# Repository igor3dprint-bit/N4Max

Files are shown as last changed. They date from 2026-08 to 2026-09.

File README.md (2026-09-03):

## ⚠️ Leia antes de qualquer coisa: o risco é seu

Este material é compartilhado de graça, como está, **sem nenhuma garantia**. Ele descreve o que deu
certo em **uma** impressora: a minha.

**Ao seguir qualquer coisa daqui, você assume integralmente a responsabilidade pelo que acontecer
com o seu equipamento.** Isso inclui, sem se limitar a: perda da configuração, impressora que não
liga mais, firmware corrompido, bico enfiado na mesa, chapa riscada, peça danificada, perda de
garantia do fabricante, e prejuízo material ou de tempo.

Nem o autor nem a S&M Makers nem os projetos citados respondem por qualquer dano, direto ou
indireto, decorrente do uso destas instruções.

Mexer em firmware, em sonda e em Z-offset **tem risco real**. Estas páginas existem justamente
porque cada coisa aqui quebrou primeiro na minha máquina. O caminho de volta está documentado em
todos os procedimentos, mas quem está com a mão na impressora é você.

Se você não se sente confortável em ler um comando antes de colar, ou não tem como voltar atrás,
**não faça**. Não tem problema nenhum em manter a impressora como ela veio de fábrica.

*This material is provided free of charge, as is, with no warranty of any kind. By following it you
accept full responsibility for anything that happens to your equipment. Neither the author nor any
project referenced here is liable for any damage, direct or indirect.*

---

# Elegoo Neptune 4 Max: Klipper moderno, BTT Eddy e o Z-offset que não obedece

Tudo o que eu aprendi mexendo na minha Neptune 4 Max, escrito comando por comando, com os números
reais que eu medi na máquina. Não é teoria de fórum: cada coisa aqui quebrou primeiro, e só depois
funcionou.

Autor: [@Igor3DPrint](https://instagram.com/igor3dprint)

[Passo a passo em português](PASSO-A-PASSO.md) · [Step by step in English](STEP-BY-STEP.md) ·
[Página web](https://igor3dprint-bit.github.io/N4Max/)

---

## Crédito antes de tudo

**Sem a S&M Makers, nada disto existiria.** Todo o trabalho de portar o Klipper moderno para a
Neptune 4 Max é dele. Este repositório traduz o processo para o português e acrescenta o que eu
descobri usando a máquina no dia a dia. Se isto te ajudou, o agradecimento vai pra lá.

| | |
|---|---|
| Vídeo | https://www.youtube.com/watch?v=Aoy3sI1lv1g, do **@SandMMakers** |
| Tutorial original | https://sandmmakers.com/Projects/Neptune4MaxLatestKlipper/Directions.html |
| Código | https://github.com/sandmmakers/klipper |

**Menção honrosa: BigTreeTech.** O hardware que faz o Z-offset se medir sozinho é deles: a sonda
BTT Eddy. Sem ela, nem a §3 nem a §4 deste guia existiriam. A minha unidade foi comprada na loja
oficial BIGTREETECH no AliExpress.

*Honorable mention: BigTreeTech, maker of the BTT Eddy probe that makes the self-measuring Z-offset
possible. My unit was bought from BigTreeTech's official store on AliExpress.*

---

## O que tem aqui

### 1. Instalar o Klipper de 2025 no lugar do de 2022

A Neptune 4 Max sai de fábrica com um Klipper de **2022**. O passo a passo leva você até a versão de
**2025**, comando por comando, explicando o que cada um faz e mostrando o que você deve ver na tela.
Sem pendrive, sem chave de fenda, sem abrir a impressora.

| 🇧🇷 PT-BR | 🇺🇸 EN |
|---|---|
| [PASSO-A-PASSO.md](PASSO-A-PASSO.md) | [STEP-BY-STEP.md](STEP-BY-STEP.md) |

### 2. Instalar e calibrar uma sonda BTT Eddy

O Eddy é rápido e preciso, e tem uma limitação que quase ninguém avisa: ele enxerga só os últimos
4 mm. Na Neptune 4 Max, onde a sonda é a única referência de Z da máquina, isso muda tudo.

Este guia cobre a montagem, as três medidas que você precisa tirar, a ordem certa da calibração, e
as quatro armadilhas que me custaram uma noite inteira e um bico arrastado na chapa. Tem ênfase
especial na **corrente de excitação do sensor**, o `reg_drive_current`, que é o parâmetro mais
importante e o menos falado. É a causa mais comum de `Eddy current sensor error` nesta máquina, e a
mensagem parece dizer que o sensor está longe da mesa. Não é isso que ela informa. Com a corrente
errada, o sensor dá erro mesmo estando na distância certa, e você procura horas no lugar errado.

| 🇧🇷 PT-BR | 🇺🇸 EN |
|---|---|
| [EDDY.md](EDDY.md) | [EDDY.en.md](EDDY.en.md) |

### 3. Fazer a máquina achar o Z sozinha, com o eddy-ng

O **BTT Eddy é o hardware**. O **eddy-ng é um software alternativo para esse mesmo hardware** —
mesma bobina, mesmo cabo, mesma peça no toolhead. O que muda é quem interpreta a leitura.

Com o driver padrão, você faz o teste do papel uma vez e guarda o número. Com o eddy-ng, **o bico
encosta na mesa e o zero é medido na hora, a cada impressão**. Isso se chama *tap*, e é o motivo
inteiro de trocar: acaba o teste do papel, e o zero fica certo mesmo trocando de bico ou saindo de
PLA a 60 °C para ABS a 100 °C, porque a medição é feita quente.

Não precisa migrar para o Klipper mainline: instala em cima do fork da S&M Makers. Aqui o tap ficou
com **desvio padrão de 0,006 mm** em três medições — seis micra — mesmo com a bobina montada a
0,94 mm, um terço da altura que a documentação recomenda.

O guia traz a receita completa, o ovo-e-galinha do primeiro homing (a sonda é a única referência de
Z e ela ainda não está calibrada), e as dez coisas que quebraram no caminho, com o que resolveu cada
uma.

| 🇧🇷 PT-BR | 🇺🇸 EN |
|---|---|
| [EDDY-NG.md](EDDY-NG.md) | [EDDY-NG.en.md](EDDY-NG.en.md) |

### 4. O Z-offset que não obedece, e por quê

Nesta máquina você ajusta o Z-offset, salva, e **quase nada muda**. Medido: mudar de `0.0` para
`2.110` deslocou o bico em **0,05 mm** quando deveria deslocar 2,11.

São três causas somadas, e nenhuma delas está documentada em outro lugar. O módulo da tela zera o
valor no `SAVE_CONFIG`, o `plr.cfg` declara a impressora zerada segundos depois de ligar sem ter
homeado, e o `PROBE_CALIBRATE` repete o mesmo valor errado. Tem a solução, como medir o **seu** valor,
e o efeito colateral que enfiou um bico na borracha de limpeza aqui.

[Z-OFFSET.md](Z-OFFSET.md), bilíngue

### 5. Uma máquina de referência inteira

O hardware montado, todos os valores gravados na configuração, cada alteração feita e o motivo dela,
as macros do dia a dia, e o que ficou pendente. É o exemplo completo: os outros documentos ensinam o
procedimento, este mostra uma máquina onde o procedimento já foi até o fim.

[MAQUINA-REFERENCIA.md](MAQUINA-REFERENCIA.md)

E os arquivos de configuração de verdade, copiados da impressora, em [config/](config/) — para você
comparar com os seus quando algo não bater. Vêm com o aviso de sempre: a estrutura serve, os números
são meus.

### 6. Uma IA que conduz você pelo processo

Jogue este repositório inteiro no Claude, no Codex ou no Cursor e peça ajuda. Antes de fazer
qualquer coisa, a IA vai te perguntar **o que você quer**:

> 1. Atualizar o Klipper &nbsp;·&nbsp; 2. Instalar o BTT Eddy &nbsp;·&nbsp; 3. Z-offset não obedece
> &nbsp;·&nbsp; 4. Diagnosticar erro de homing &nbsp;·&nbsp; 5. Macros e qualidade de impressão
> &nbsp;·&nbsp; 6. Migrar para o eddy-ng

Você escolhe, e ela carrega só o documento daquele caminho, segue a ordem certa, e obedece às regras
de segurança que existem porque cada uma custou um prejuízo real aqui. Ela também tem a máquina de
referência acima para explicar de onde vem cada número, em vez de chutar.

Como a IA conduz o trabalho

Funciona com Claude Code, Codex, Cursor, Copilot e qualquer agente que leia um arquivo de contexto
do repositório.

[AGENTS.md](AGENTS.md) · [CLAUDE.md](CLAUDE.md)

---

## O caminho curto

```bash
# 1. entrar na impressora (senha padrao de fabrica: makerbase)
ssh mks@SEU_IP

# 2. descobrir o firmware Elegoo instalado
grep -rhoE "1\.[0-9]+\.[0-9]+\.[0-9]+" /home/mks/Desktop/myfile/ 2>/dev/null | sort | uniq -c | sort -rn | head -1

# 3. ver quais versoes do port existem para ele
git ls-remote --tags https://github.com/sandmmakers/klipper.git | grep -oE 'sandmmakers-[A-Za-z0-9.-]+' | grep -v '\^{}' | sort -u
```

A partir daqui, siga o [passo a passo](PASSO-A-PASSO.md). Os próximos comandos mexem na máquina e a
ordem importa.

---

## Estrutura

| Arquivo | Conteúdo |
|---|---|
| `PASSO-A-PASSO.md` | Guia completo de instalação do Klipper, comando por comando |
| `STEP-BY-STEP.md` | O mesmo guia, em inglês |
| [EDDY.md](EDDY.md) · [EDDY.en.md](EDDY.en.md) | Instalação e calibração do BTT Eddy, com as armadilhas |
| [EDDY-NG.md](EDDY-NG.md) · [EDDY-NG.en.md](EDDY-NG.en.md) | Trocar o driver do Eddy pelo eddy-ng: tap, Z-offset automático, e os 10 erros do caminho |
| `config/` | Os arquivos de configuração reais da máquina, sanitizados |
| `Z-OFFSET.md` | O Z-offset que não obedece: causas, solução, medição. Bilíngue |
| `MAQUINA-REFERENCIA.md` | A máquina do autor por inteiro: hardware, valores, alterações, macros |
| `AGENTS.md` | Instruções para uma IA conduzir qualquer um dos seis caminhos |
| `CLAUDE.md` | Ponteiro de uma linha para o `AGENTS.md` |
| `docs/` | A página web deste repositório |

---

## Por que comandos, e não um instalador de um clique

Um instalador promete "clica e funciona". Essa promessa exige testar a instalação inteira numa
máquina de fábrica, várias vezes, e eu tenho uma impressora só, em produção.

Comando na tela promete outra coisa: **você está no comando, aqui está o que vai rodar e por quê.**
Essa promessa eu consigo sustentar. Você lê antes de colar, entende o que mudou, e sabe onde parar se
algo sair diferente do esperado. De quebra funciona em Mac e Linux, não só Windows.

---

## Um aviso sobre os números deste repositório

Todo valor numérico aqui foi medido na minha máquina. Os que mais mudam de impressora para
impressora são `x_offset`, `y_offset`, `z_offset`, `reg_drive_current`, a altura de montagem da
sonda e o ponto usado no homing.

Copiar esses números direto, sem medir, é a forma mais rápida de reproduzir os meus erros em vez dos
meus acertos. Use a explicação, meça o seu.

---

## English

This repository documents three things about the Elegoo Neptune 4 Max: installing modern Klipper
over the factory 2022 build, installing and calibrating a BTT Eddy probe, and fixing the Z-offset
that refuses to obey when you save it.

The Klipper install guide, the Eddy guides, and the Z-offset write-up are available in English. The
reference machine and the AI instructions are currently Portuguese only, but any AI agent reading this
repository will answer you in English.

[STEP-BY-STEP.md](STEP-BY-STEP.md) · [EDDY.en.md](EDDY.en.md) · [EDDY-NG.en.md](EDDY-NG.en.md) ·
[Z-OFFSET.md](Z-OFFSET.md)

All the porting work belongs to [S&M Makers](https://github.com/sandmmakers/klipper). This repository
walks through their process and adds what I found living with the machine.

---

## Licença e garantia

Código sob [MIT](LICENSE). O Klipper em si é GPLv3, e o port é da S&M Makers, sob a licença dele.

**Sem garantia, e a responsabilidade é sua.** Como está escrito no topo desta página: ao seguir
qualquer procedimento daqui, você assume integralmente o risco e as consequências para o seu
equipamento. O autor não responde por dano de nenhum tipo.

Mexer em firmware e em sonda tem risco. O caminho de volta existe e está documentado, mas quem está
do lado da impressora é você. Vá devagar, leia antes de colar, e pare quando ficar estranho.

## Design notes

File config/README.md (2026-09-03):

# Os arquivos reais da minha Neptune 4 Max

Esta pasta é o acervo: a configuração **de verdade** da máquina onde este repositório foi escrito,
copiada da impressora, não digitada à mão para o tutorial. Serve para você comparar quando algo não
bate, ou para ver como uma coisa ficou depois de pronta.

Estado destes arquivos: **03/09/2026**, com Klipper da S&M Makers rodando em Python 3, BTT Eddy com
o driver [eddy-ng](../EDDY-NG.md), e a borracha de limpeza já removida da máquina.

---

## ⚠️ Leia antes de copiar qualquer coisa

**Estes arquivos não servem para colar na sua impressora.** Sério. Alguns valores aqui são medidas
físicas da *minha* montagem, e usar os meus é a forma mais rápida de enfiar um bico na sua chapa:

| Valor | Por que é só meu |
|---|---|
| `x_offset` / `y_offset` | Depende de qual adaptador você imprimiu e de como ele ficou |
| `reg_drive_current` / `tap_drive_current` | Sai da calibração da *sua* bobina, na *sua* altura |
| `calibration_17` / `calibration_18` | A curva medida do meu sensor. Não tem significado no seu |
| `[bed_mesh default]` | O empeno da minha chapa |
| `position_endstop`, limites dos eixos | Da minha máquina, com as minhas peças |
| `serial:` do Eddy | Foi trocado por um marcador. O seu sai de `ls /dev/serial/by-id/` |

Use como **referência de estrutura e de ordem**: onde a seção fica, o que vem antes do quê, como um
comentário explica a decisão. Os números, meça os seus.

---

## O que tem em cada arquivo

| Arquivo | O que é |
|---|---|
| `printer.cfg` | A configuração principal. ~1.200 linhas, com os comentários de cada decisão e a data. É o arquivo mais útil aqui, e o mais perigoso de copiar |
| `eddy.cfg` | Só o BTT Eddy: MCU, a seção `[probe_eddy_ng]` e o `[bed_mesh]`. Incluído pelo `printer.cfg` |
| `eddyng_macros.cfg` | As macros do fluxo novo: `PRINT_START` com tap, `LINHA_KAMP` (purga) e `ZoffNGEddy` (z-offset guiado). Incluído por último, de propósito |
| `moonraker.conf` | Praticamente de fábrica. Está aqui só para mostrar que não precisa de mágica |
| `plr.cfg` | Recuperação de queda de energia, da Elegoo. **Não é meu e tem armadilha** — veja abaixo |
| `KAMP_Settings.cfg` | Herança do KAMP. O include está **desligado** hoje; a purga é a `LINHA_KAMP` |

---

## Três coisas para reparar quando for ler

**1. O `printer.cfg` é um diário, não um arquivo limpo.** Cada bloco tem um comentário com a data e
o motivo. Isso é de propósito: seis meses depois, o comentário é a única coisa que explica por que
aquele número é aquele. Vale mais que um arquivo bonito. Repare especialmente no `[stepper_z]`, que
tem um aviso comprido sobre um quase-acidente.

**2. Tem macro obsoleta lá dentro, e ela ficou de propósito.** `LIMPAR_BICO`, `PURGA_BAMBU`,
`LINHA_PURGA` e `EDDY_OFFSET_FULL` eram do tempo da borracha de limpeza, que **não existe mais na
máquina**. Nada chama elas hoje. Deixei porque o histórico ensina — mas se você copiar o
`printer.cfg` inteiro achando que está tudo ativo, vai se perder.

**3. `MANTER_MESA_50` mantém a mesa a 50 °C o tempo todo.** É um `[delayed_gcode]` que se re-arma a
cada 60 segundos. Foi decisão minha (a mesa desta máquina demora muito para aquecer), e me enganou
depois: passei uma sessão inteira achando que a mesa esquentava sozinha por bug. Se você copiar isso
sem querer, sua mesa vai ficar ligada para sempre. Comente o bloco.

**4. O `plr.cfg` zera o Z-offset.** O `RESUME_INTERRUPTED` começa com `SET_GCODE_OFFSET Z=0` e **não
passa por `G28`**. Retomar uma impressão depois de queda de luz continuava com o offset zerado até o
fim. Com o eddy-ng isso importa menos (o zero vem do tap), mas o arquivo está aqui inteiro para você
ver o que a Elegoo colocou na máquina.

---

## Como comparar com a sua

Em vez de abrir os dois lado a lado, baixe o seu e faça o diff só da seção que te interessa:

```bash
# baixe o seu (pelo Moonraker, sem precisar de SSH)
curl -s "http://SEU_IP/server/files/config/printer.cfg" -o meu-printer.cfg

# compare só uma seção
diff <(sed -n '/^\[stepper_z\]/,/^\[/p' meu-printer.cfg) \
     <(sed -n '/^\[stepper_z\]/,/^\[/p' printer.cfg)
```

---

## Sobre privacidade

Estes arquivos foram varridos antes de subir: sem senha, sem token, sem chave, sem rede de casa, sem
e-mail. O único identificador de hardware que existia — o número de série USB do Eddy — foi trocado
por um marcador, e de todo jeito você precisa do **seu**.

A senha `makerbase` que aparece nos guias é a de fábrica da Elegoo, igual em toda Neptune. Se a sua
impressora fica exposta na internet, troque — mas isso vale desde antes deste repositório existir.

---

Crédito do Klipper moderno nesta máquina: [S&M Makers](https://github.com/sandmmakers/klipper).

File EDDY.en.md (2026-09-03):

# BTT Eddy Duo on the Elegoo Neptune 4 Max

Author [@Igor3DPrint](https://instagram.com/igor3dprint)

> **This guide uses the driver that comes with Klipper (`probe_eddy_current`), and it is still valid:
> this is where you start.** Two things changed on the reference machine after it was written, on
> 03/09/2026, and you should know them before reading:
>
> - It moved to **[eddy-ng](EDDY-NG.en.md)**, where the Z-offset measures itself on every print. If
>   your final goal is to stop calibrating Z, install it first by following this document and then go
>   to [EDDY-NG.en.md](EDDY-NG.en.md).
> - The **nozzle-cleaning pad was removed** from the machine. The nozzle-cleaning macros mentioned
>   later (`LIMPAR_BICO`, `PURGA_BAMBU`, `EDDY_OFFSET_FULL`) still exist in the configuration, but
>   nothing calls them anymore. They are not an error; they are history.

This guide covers installing the BTT Eddy Duo probe on the Neptune 4 Max running modern Klipper. It
is written in the order things happen, with the numbers I measured on my machine and the mistakes I
made before reaching them.

A summary before anything else. The parameter that cost me the most time was the coil drive current,
`reg_drive_current`. With it wrong, the sensor reports a failure even with the nozzle at the right
distance, and the error message points to the wrong place. It is in [topic 9](#9-the-drive-current).

> Saw `Eddy current sensor error`? Run `LDC_CALIBRATE_DRIVE_CURRENT CHIP=btt_eddy` before changing
> any height. The command does not move the machine, so it is safe to run at any time, and this is the
> most common cause of that error on this machine. Full detail in [topic 9](#9-the-drive-current).

---

## Topics

1. [Hardware I used](#1-hardware-i-used)
2. [Printed part](#2-printed-part)
3. [How the Eddy appears on the computer](#3-how-the-eddy-appears-on-the-computer)
4. [What the Eddy does and does not do](#4-what-the-eddy-does-and-does-not-do)
5. [The three mounting measurements](#5-the-three-mounting-measurements)
6. [The base configuration](#6-the-base-configuration)
7. [The calculations that prevent sensor errors](#7-the-calculations-that-prevent-sensor-errors)
8. [The calibration order](#8-the-calibration-order)
9. [The drive current](#9-the-drive-current)
10. [Four Neptune 4 Max traps](#10-four-neptune-4-max-traps)
11. [Homing and the first-home ritual](#11-homing-and-the-first-home-ritual)
12. [The dense mesh](#12-the-dense-mesh)
13. [Macros I use day to day](#13-macros-i-use-day-to-day)
14. [How to measure whether the calibration came out good](#14-how-to-measure-whether-the-calibration-came-out-good)
15. [Symptom table](#15-symptom-table)

---

## 1. Hardware I used

**BTT Eddy Duo** probe, from BigTreeTech. The Duo version connects over **USB**, directly to the
printer board or to the host. It does not need a data wire connected to the Neptune motherboard,
which simplifies the installation a lot.

It appears in Klipper as a separate MCU, with its own serial.

```ini
[mcu eddy]
serial: /dev/serial/by-id/usb-Klipper_rp2040_SEU_ID_AQUI-if00
```

To discover your ID, with the probe plugged in, run this inside the printer.

```bash
ls /dev/serial/by-id/
```

---

## 2. Printed part

The mount that holds the Eddy on the Neptune 4 extruder carriage, the only STL needed for this
build.

https://www.printables.com/model/928061-neptune-4-btt-eddy-adapter

Print it in **ABS or ASA**. The part sits close to the hot nozzle and near the heated bed, and PLA
softens and deforms in that temperature range, which takes the precision out of the geometry that
holds the probe. PETG is a middle ground and still creeps under sustained heat.

There are two variants in the model, one straight and one at ninety degrees. I printed and used the
straight one. Choose based on the clearance left on your carriage, because the variant changes the
adapter position and with it the coil mounting height, and that height goes into every calculation
in [topic 7](#7-the-calculations-that-prevent-sensor-errors). Measure your height after mounting. Do
not copy mine.

It takes **2 M3 heat-set inserts**, melted in with a soldering iron.

---

## 3. How the Eddy appears on the computer

This point deserves attention because it is where many people get stuck before even starting.

The **BOOT button on the Eddy Duo is on the top side of the board**. It does not appear on the
computer by itself when you only plug in the cable. The sequence that works is this.

1. With the USB cable disconnected, press and hold the BOOT button
2. Without releasing the button, plug the USB cable into the computer
3. Release the button

Eddy Duo BOOT button sequence: USB disconnected, hold the button, plug in USB, release the button

Now it appears, and you can flash Klipper firmware to it.

If you plug in USB first and only then press the button, it does not enter flashing mode. That is
what happened to me on the first try, and I spent a while thinking the board was defective.

After it is flashed, it starts appearing normally in `/dev/serial/by-id/` every time the printer
turns on, without needing any button.

---

## 4. What the Eddy does and does not do

The Eddy measures distance through eddy current induced in a coil. It reads fast, repeats well, and
does not touch anything.

The limitation almost nobody warns you about is range. It sees **only the last few millimeters**. On
my machine, the calibrated range goes from 0.05 mm to 4.05 mm. Above that, the chip does not see the
bed, sets the error bits, and Klipper aborts.

That leads to the sentence that summarizes the whole guide.

> The Eddy does not work by itself as a Z endstop.

A mechanical endstop triggers from any height. The Eddy does not trigger, because from far away there
is no reading to compare.

On the Neptune 4 Max this matters, because the factory `[stepper_z]` uses
`endstop_pin: probe:z_virtual_endstop`, meaning the probe is the only Z reference the machine has.
If you remove the original probe when installing the Eddy, as I did, you create a loop. To home, the
nozzle needs to be close, and to know it is close, Z needs to be homed.

[Topic 11](#11-homing-and-the-first-home-ritual) shows how to break that loop. If you can keep the
original probe installed in parallel, keep it, and you skip that entire topic.

One detail fooled me. After removing the old probe, its pin remains on the board and remains being
read. An input with a pull-up resistor and nothing plugged in floats high, which makes Klipper
believe an endstop is triggered. Do not trust what the pin reports; trust what is bolted to the
machine.

> **Do not try to use the removed probe's pin as an endstop.** I tried it here, pointing
> `[stepper_z]` to the old probe pin with the end empty. The axis went down and did not stop, because
> the pin held high by pull-up never changes state, and I had to cut power to the printer. Only use
> that pin again after you have a real sensor bolted to its end.

---

## 5. The three mounting measurements

After bolting the adapter on, you need three numbers. Getting any of them wrong makes the whole mesh
measure the wrong place.

### Coil height

Touch the nozzle to the bed and measure how far the face of the coil sits above the tip of the
nozzle. Mine was **0.94 mm**. BigTreeTech recommends between two and three millimeters.

I went lower by choice, and that reduces maneuvering clearance. With 0.94 mm, when the nozzle is
three millimeters from the bed, the coil is at 3.94 mm, almost at the 4.05 mm limit it can see.

Save that number, because it goes into every calculation in the next topic.

```
coil height = nozzle height + mounting height
```

Side view of the coil, the bed, and the 0.05 to 4.05 mm reading range

The image shows why a probing descent that starts above that range fails on the first sample: the
chip has no reading to compare at that height.

### X offset

Measure from the center of the nozzle to the center of the coil, horizontally. Mine measured
**33.34 mm**.

The sign is confusing. The rule I use is to look at `[stepper_x]` in `printer.cfg`. With
`position_endstop: 0` and `homing_positive_dir: false`, the endstop is on the side where X equals
zero, meaning the left side. If the coil is on the same side as the endstop, it sits left of the
nozzle, and `x_offset` is **negative**.

In my case it became `x_offset: -33.34`.

### Y offset

This is the one almost everyone assumes is zero. I assumed that too, and later redid a whole mesh
because of it. Measure.

On mine, the Eddy sits **behind** the nozzle and measured **20 mm**. Behind means the coil covers a
point on the plate with a larger Y than the nozzle's Y, so `y_offset` is **positive**.

In my case it became `y_offset: 20`.

I ran a full mesh with `y_offset` at zero when the correct value was twenty. Every point was measured
twenty millimeters away from its intended place. The mesh looked normal on screen and was wrong
everywhere.

---

## 6. The base configuration

I keep the Eddy in a separate file called `eddy.cfg`, with an `[include eddy.cfg]` in `printer.cfg`.
That makes it easier to compare and roll back.

```ini
[mcu eddy]
serial: /dev/serial/by-id/usb-Klipper_rp2040_SEU_ID_AQUI-if00

[probe_eddy_current btt_eddy]
sensor_type: ldc1612
i2c_mcu: eddy
i2c_bus: i2c0f
x_offset: -33.34
y_offset: 20
speed: 5.0
samples: 2
samples_result: median
sample_retract_dist: 1.0

[bed_mesh]
speed: 200
horizontal_move_z: 2.5
mesh_min: 20,25
mesh_max: 390,410
probe_count: 6,6
algorithm: bicubic
bicubic_tension: 0.2
mesh_pps: 2, 2
fade_start: 5.0
fade_end: 30.0
```

Notice that **there is no `z_offset` in this block**, and that is intentional. The reason is in
[trap 4](#trap-4-z_offset-written-by-hand-locks-save_config).

### Why mesh_max does not cover the whole plate

The plate is 420 mm, but the measurable area is smaller, and the probe geometry is why. Klipper
calculates it like this.

```
nozzle position = mesh point minus the axis offset
```

With `x_offset: -33.34`, the nozzle needs to go to `point + 33.34`. X `position_max` is 430.1, so the
rightmost measurable point is around 396. I use 390 to leave margin, which takes the nozzle to
423.34.

With `y_offset: 20`, the nozzle goes to `point - 20`. A Y `mesh_min` of 25 takes the nozzle to 5,
almost touching the front stop.

The lower X limit has a reason too. With `mesh_min` in X below 20, the coil would pass over the
cleaning pad, which is seven millimeters tall, during the scan.

Top view of the plate, with the nozzle position against the coil position and the resulting mesh area

---

## 7. The calculations that prevent sensor errors

Three inequalities. Call `F` the top of the calibrated range, which on my machine is 4.05, and `M`
the coil mounting height, which on mine is 0.94.

```
z_offset + sample_retract_dist   <  F
horizontal_move_z + M            <  F
starting height for the descent + M <  F
```

If any of them overflows, the sensor will report an error at some point in the cycle, and the symptom
will look like something completely different.

### First calculation, sample_retract_dist

With `samples: 2`, Klipper probes, rises by this amount, and probes again. The trigger happens with
the coil reading the `z_offset` value. If the retract is too large, the second probe starts outside
the range.

The factory default is 3.0. With `z_offset` near 2.0, that gives 5.0 and overflows. I use **1.0**.

### Second calculation, horizontal_move_z

This is the nozzle height while traveling between mesh points. Add the mounting height to know where
the coil is.

The ten-millimeter default would put the coil at 10.94 mm, blind. I use **2.5**, which results in
3.44 mm.

### Third calculation, the starting height for the descent

This is defined by the `z_hop` in `safe_z_home`, or by your `homing_override`. With a 0.94 mm mount,
starting the descent at three millimeters leaves the coil at 3.94 mm, inside the range but with
little margin.

---

## 8. The calibration order

This is the part I did in the wrong order and that cost me a whole night.

1. Write the base configuration with the measured offsets
2. Calibrate the drive current with `LDC_CALIBRATE_DRIVE_CURRENT CHIP=btt_eddy` and run
   `SAVE_CONFIG`
3. Only then build the table with `PROBE_EDDY_CURRENT_CALIBRATE CHIP=btt_eddy` and run `SAVE_CONFIG`
4. Test homing
5. After that, the mesh

Never the opposite, and never only one of the two calibrations.

The drive current defines the signal amplitude, and changing it shifts all frequencies. If you build
the table first and change the current afterward, the table is no longer valid.

The worst part is that it does not warn you. It starts triggering at the wrong height, which means
nozzle against the sheet.

> Changed `reg_drive_current`, the table is dead. Redo `PROBE_EDDY_CURRENT_CALIBRATE` before sending
> any `G28`.

---

## 9. The drive current

**This is the parameter that knocks the most people down on this machine.** If you came here directly
from a sensor error, read this whole topic before changing any height, retract, or offset.

The LDC1612 excites the coil with a configurable current called `reg_drive_current`, which is an
integer from zero to thirty-one. It needs to match your coil, your mounting height, and your bed.

Current that is **too high** saturates the amplitude. Current that is **too low** kills the signal.
In both cases, the chip sets an error bit and Klipper returns this.

```
Error during homing z: Eddy current sensor error
```

Here is the trap. That message sounds like it says the sensor is far from the bed, and that is not
what it reports. In my case the nozzle was at two millimeters, inside the range, and the error still
happened. I spent hours changing height, bed temperature, and retract distance, when the problem was
the signal gain.

If you want to confirm at the source, the error starts in the firmware, in `src/sensor_ldc1612.c`.

```c
if (data > 0x0fffffff) {
    // Sensor reports an issue - cancel homing
    ld->homing_flags = 0;
    trsync_do_trigger(ld->ts, ld->error_reason);
    return;
}
```

The four high bits are the chip's own error bits. Notice that the test comes **before** any movement,
so it aborts on the first sample. That is why the symptom looks like "it does not go down and already
errors". Also notice that this has no relation to the `calibrate` table, because the hardware is
complaining; Klipper is not comparing numbers.

### How to measure without moving the machine

There is a command that makes the chip itself choose the right value, in the position where it
already is, without moving anything.

```
LDC_CALIBRATE_DRIVE_CURRENT CHIP=btt_eddy
```

The response appears in the console.

```
probe_eddy_current btt_eddy: reg_drive_current: 16
```

Compare it with what is in your configuration. In my case it was eighteen and the chip wanted
sixteen. A two-point difference locked everything up.

The number is not fixed forever. After remounting the probe and remeasuring `x_offset` and
`y_offset`, I ran the command again and it pointed back to eighteen. Treat any value in this guide as
a snapshot, not a constant. Every time the physical mount changes, measure again before trusting the
old number, yours or mine.

### Where this command lives

If you look for this command inside `probe_eddy_current.py`, you will not find it, and it is easy to
conclude your Klipper fork does not have it. It lives in `ldc1612.py`, which is the chip driver.

```bash
grep -n "LDC_CALIBRATE_DRIVE_CURRENT" ~/klipper*/klippy/extras/ldc1612.py
```

I almost abandoned this line of investigation because I searched in the wrong file.

### After measuring

Run `SAVE_CONFIG`. The printer restarts with the new value. Then redo the table, as shown in
[topic 8](#8-the-calibration-order). Do not skip that part.

---

## 10. Four Neptune 4 Max traps

Listed in the order they appeared here, because one hid the next. If you have
`Eddy current sensor error` and already checked the height, it is very likely one of these.

### Trap 1, the printer declares itself zeroed at boot

In the Neptune `printer.cfg` and `plr.cfg`, this block exists.

```ini
[delayed_gcode KINEMATIC_POSITION]
initial_duration: 3.0
gcode:
      SET_KINEMATIC_POSITION X=110
      SET_KINEMATIC_POSITION Y=110
      SET_KINEMATIC_POSITION Z=0
```

A few seconds after power-up, Klipper starts believing Z is at zero, with the nozzle physically
thirty millimeters from the bed. When you send `G28`, `safe_z_home` concludes Z is already homed,
that zero is lower than `z_hop`, and **raises** the nozzle to "three", which in real life is
thirty-three. The coil sees nothing and aborts.

The symptom is very characteristic. It homes X and Y, returns to the middle, does not descend, and
immediately errors.

Comment out the whole block in both files. It appears duplicated, and the one that counts is the one
in `printer.cfg`, because it comes later in the read order. Commenting only one does not solve it.

The same block is also the root cause of the Z-offset that appears ignored on this machine, with the
full explanation in
[Z-OFFSET.md](Z-OFFSET.md#2-a-impressora-se-declara-zerada-alguns-segundos-depois-de-ligar-sem-ter-homeado).

### Trap 2, an old Z compensation applied blindly

I had this in `printer.cfg`, from when I used the contact probe.

```ini
[gcode_macro G28]
rename_existing: G28.1
gcode:
    G28.1 {rawparams}
    SET_GCODE_OFFSET Z=-1.95
```

After changing probes, it kept being applied. Every `G0 Z` started going down 1.95 mm more than I
commanded. That is how I dragged the nozzle across the sheet while trying to position manually.

Check the active value on your machine now.

```bash
curl -s "http://SEU_IP/printer/objects/query?gcode_move" | grep -o '"homing_origin": \[[^]]*\]'
```

If the third number is not `0.0`, there is a hidden offset eating into your descent. Zero it before
sending any manual Z movement.

### Trap 3, the retract between the two homing passes

`[stepper_z]` comes with `homing_retract_dist: 5`.

Klipper hits the trigger, rises by that much, and makes a second slow pass to confirm. With the
trigger at two millimeters of reading, rising five takes the coil to seven, outside the range. The
second pass starts blind and the chip aborts.

The symptom is deceptive because the **first pass works**. You see the machine descend, touch, and
only then error. It looks like a trigger problem and is a retract problem.

I use **1.5**, which leaves the coil at 3.5 mm.

### Trap 4, z_offset written by hand locks SAVE_CONFIG

If you write `z_offset` in `eddy.cfg`, which is an included file, every `SAVE_CONFIG` after a
`PROBE_CALIBRATE` will fail with this message.

```
SAVE_CONFIG section 'probe_eddy_current btt_eddy' option 'z_offset' conflicts with included value
```

Klipper does not autosave over a value that came from an include. Calibration runs, shows the new
number, and cannot save it.

The solution is to leave `z_offset` out of `eddy.cfg` and allow it to live in the autosave block at
the end of `printer.cfg`. If you are migrating from a configuration that already had the value
written by hand, remove the line from the included file and add the value to the autosave block.

```
#*# [probe_eddy_current btt_eddy]
#*# z_offset = 0.300
#*# reg_drive_current = 18
```

---

## 11. Homing and the first-home ritual

If your original probe was removed, the first `G28` after power-up cannot work by itself, because
there is no Z reference and the coil only sees four millimeters.

The cycle without a contact probe, and how to break it

What works, and is safe, is homing X and Y first and then **descending while watching**.

```
G28 X Y
G0 X215 Y215 F6000
```

Now lower Z from the panel, watching the nozzle, until it is about two millimeters from the bed. Use
steps of ten only while it is clearly far away, then one, then zero point one. Then:

```
G28 Z
```

After that, Z is homed, and the printer works normally until you turn it off.

> Never send an absolute `G0 Z` to a height calculated in your head while Z is not trustworthy. That
> is exactly how I dragged the nozzle. Small step, eyes on the nozzle, and stop if it touches.

### Separating travel clearance from descent height

If you have something tall on the bed near the origin, like the cleaning pad, the `z_hop` in
`safe_z_home` creates a deadlock. It is both the travel clearance to the endstop and the starting
height for the descent. You need high clearance for travel and low height for probing, and one number
does not solve both.

The way out is to replace `safe_z_home` with a `homing_override`.

```ini
[homing_override]
axes: xyz
gcode:
    {% set tudo = 'X' not in params and 'Y' not in params and 'Z' not in params %}
    {% set z_tinha_referencia = 'z' in printer.toolhead.homed_axes %}
    {% if not z_tinha_referencia %}
        SET_KINEMATIC_POSITION Z=0
    {% endif %}
    G91
    G0 Z16 F600
    G90
    {% if tudo or 'X' in params %}
        G28 X
    {% endif %}
    {% if tudo or 'Y' in params %}
        G28 Y
    {% endif %}
    {% if tudo or 'Z' in params %}
        {% if not z_tinha_referencia %}
            { action_raise_error("Z has no reference. The Eddy only sees up to 4mm, so blind descent does not work. X and Y are already homed. Lower the nozzle from the panel to about 2mm from the bed and run G28 Z.") }
        {% endif %}
        G0 X239.25 Y194.55 F6000
        G91
        G0 Z-16 F600
        G90
        G28 Z
    {% endif %}
```

Adjust `G0 X239.25 Y194.55` to your machine's probing point.

This version gained a guard. When Z has no reference at all, it homes X and Y normally and **stops**,
with written instructions instead of diving blindly. That turns a confusing `Eddy current sensor
error` into a message that says what to do: lower the nozzle from the panel until it is near the bed
and run `G28 Z` by hand, as described at the start of this topic.

The logic in plain English. It rises sixteen millimeters relative, which is safe from any height,
including with virgin Z. It homes X and Y with full clearance over the pad. It returns to the probing
point. It descends the same sixteen millimeters relative, putting the nozzle exactly back at the
height it left from. Then it probes.

Notice that **there is no descent to an absolute height** inside here. I did write a version that
descended to Z equal to three when Klipper thought Z was known, and that is dangerous, because a
reference declared by hand with `SET_KINEMATIC_POSITION` also counts as known. The descent would turn
into a dive of dozens of millimeters into the bed.

Whoever knows Z itself is trustworthy, like a print-start macro that just homed, positions itself
before calling `G28 Z`.

`safe_z_home` and `homing_override` cannot coexist. Comment out one to use the other.

---

## 12. The dense mesh

A contact probe takes almost a second per point. The Eddy scans in continuous motion, and this is
where it pays for itself. You can measure thousands of points in the time the bed takes to stabilize.

```ini
[gcode_macro EDDY_MALHA]
description: Dense mesh of the whole usable area. Ex, EDDY_MALHA BED=50 SOAK=300
variable_pontos: 70
gcode:
    {% set c = printer['gcode_macro EDDY_MALHA'] %}
    {% set bed = params.BED|default(50)|float %}
    {% set soak = params.SOAK|default(300)|int %}
    {% set n = params.PONTOS|default(c.pontos)|int %}
    M117 Heating the bed
    M140 S{bed}
    TEMPERATURE_WAIT SENSOR=heater_bed MINIMUM={bed - 1} MAXIMUM={bed + 1}
    M117 Soak
    G4 P{soak * 1000}
    M117 Homing
    G28
    BED_MESH_CLEAR
    M117 Scanning the bed
    _BED_MESH_CALIBRATE METHOD=rapid_scan HORIZONTAL_MOVE_Z=2.5 PROBE_COUNT={n},{n} MESH_PPS=0 SCAN_SPEED=200
    M400
    RESPOND TYPE=command MSG="Mesh ready. Run SAVE_CONFIG to save."
```

Normal use.

```
EDDY_MALHA
SAVE_CONFIG
```

That is 4900 points over an area of 370 by 385 millimeters, about 5.3 mm spacing. Against the factory
six by six, which gives seventy-three millimeters of spacing, the difference is large.

Three notes that apply to any machine.

`rapid_scan` is only enabled when the probe is of type `probe_eddy_current`. With a contact probe,
Klipper falls back to the normal method without warning.

`HORIZONTAL_MOVE_Z` is the **nozzle** height during the scan, not the coil height. Redo the
calculation from [topic 7](#7-the-calculations-that-prevent-sensor-errors) with your mounting
height.

The routine time is mostly soak, and soak is what makes the mesh worth anything. A cold bed measures
one surface; a stabilized bed measures another. A half-hour routine with five minutes of scanning is
time well spent.

---

## 13. Macros I use day to day

### Nozzle cleaning on the pad

Runs the nozzle over the silicone pad. Accepts parameters so it can be reused in other contexts.

```ini
[gcode_macro LIMPAR_BICO]
description: Cleans the nozzle on the pad
variable_x: 2.5
variable_y_ini: 5
variable_y_fim: 30
variable_z: 6.0
variable_passadas: 10
variable_temp: 150
gcode:
    {% set c = printer['gcode_macro LIMPAR_BICO'] %}
    {% set t = params.TEMP|default(c.temp)|float %}
    {% set n = params.PASSADAS|default(c.passadas)|int %}
    {% if 'xyz' not in printer.toolhead.homed_axes %}
        { action_raise_error("LIMPAR_BICO, axes not homed") }
    {% endif %}
    {% if t > 0 %}
        M109 S{t}
    {% endif %}
    G90
    G0 Z{c.z + 6} F1200
    G0 X{c.x} Y{c.y_ini} F6000
    G0 Z{c.z} F600
    {% for i in range(n) %}
        G0 Y{c.y_fim} F6000
        G0 Y{c.y_ini} F6000
    {% endfor %}
    G0 Z{c.z + 10} F1200
```

With `TEMP=0`, it does not change temperature, which allows calling it in the middle of a print.

`variable_z` sits one millimeter below the height of the pad, which gives the interference that makes
the scraping happen. With a seven-millimeter pad, I use six.

### Block purge in the dead corner

Drops old filament in a corner and then cleans the nozzle. It is the Bambu collector idea adapted.

```ini
[gcode_macro PURGA_BAMBU]
description: Block purge in the corner and clean the nozzle. Ex, PURGA_BAMBU Q=50
variable_x: 0
variable_y: 45
variable_z: 15
variable_quantidade: 50
variable_velocidade: 150
variable_altura_segura: 15
gcode:
    {% set c = printer['gcode_macro PURGA_BAMBU'] %}
    {% set q = params.Q|default(c.quantidade)|float %}
    {% if 'xyz' not in printer.toolhead.homed_axes %}
        { action_raise_error("PURGA_BAMBU, axes not homed") }
    {% endif %}
    {% if printer.extruder.temperature < 170 %}
        { action_raise_error("PURGA_BAMBU, nozzle too cold to extrude") }
    {% endif %}
    SAVE_GCODE_STATE NAME=purga_bambu
    G90
    G0 Z{c.altura_segura} F1200
    G0 X{c.x} Y{c.y} F6000
    G0 Z{c.z} F600
    M83
    G1 E{q} F{c.velocidade}
    G1 E-1.5 F2100
    G4 P1500
    G0 Z{c.altura_segura} F1200
    LIMPAR_BICO TEMP=0 PASSADAS=4
    G92 E0
    RESTORE_GCODE_STATE NAME=purga_bambu MOVE=1 MOVE_SPEED=200
```

Purge height changes the result a lot. At two millimeters, the material forms a blob stuck to the
sheet. At fifteen millimeters, it comes out as a strand and barely touches, which is close to Bambu's
behavior. I use fifteen.

I took the volume from the Bambu Lab A1's own start gcode, which runs `G1 E50 F200`. It repeats that
block twice when changing material in the AMS. With no color change, one block is enough.

### Purge line in the dead strip

The block purge alone is not enough to prime the nozzle for the first layer, so I added a purge line
in the strip the mesh does not cover.

```ini
[gcode_macro LINHA_PURGA]
description: Purge line in the dead strip on the left side of the bed
variable_x_ida: 2.5
variable_x_volta: 3.1
variable_y_ini: 60
variable_y_fim: 300
variable_z: 0.4
variable_extrusao: 52
gcode:
    {% set c = printer['gcode_macro LINHA_PURGA'] %}
    G90
    M83
    G0 X{c.x_ida} Y{c.y_ini} Z{c.z} F6000
    G1 Y{c.y_fim} E{c.extrusao} F1200
    G0 X{c.x_volta}
    G1 Y{c.y_ini} E{c.extrusao} F1200
    G92 E0
```

It runs at X2.5, with the return pass at X3.1, from Y60 to Y300, at 0.4 mm height, with E52 per pass.
That is double the normal flow, on purpose.

The position is not accidental. `mesh_min` in X is 20, so everything below that is already outside
the mesh. The strip starts at Y60, twenty-five millimeters after the end of the cleaning pad, which
occupies up to Y35.

### Live z-offset adjustment

The probe `z_offset` has the sign inverted compared with intuition. A larger value moves the nozzle
closer to the bed. I got that direction wrong the first time and almost crashed the nozzle, so I
wrapped it in macros whose names describe what happens to the nozzle.

```ini
[gcode_macro SOBE]
description: Moves the nozzle away from the bed. Ex, SOBE P=0.05
gcode:
    {% set p = params.P|default(0.02)|float %}
    {% set m = 1 if 'z' in printer.toolhead.homed_axes else 0 %}
    SET_GCODE_OFFSET Z_ADJUST={p} MOVE={m}

[gcode_macro DESCE]
description: Moves the nozzle closer to the bed. Ex, DESCE P=0.05
gcode:
    {% set p = params.P|default(0.02)|float %}
    {% set m = 1 if 'z' in printer.toolhead.homed_axes else 0 %}
    SET_GCODE_OFFSET Z_ADJUST=-{p} MOVE={m}

[gcode_macro ZOFFSET_SALVAR]
description: Saves the session adjustment into the probe z_offset and restarts
gcode:
    {% if printer.gcode_move.homing_origin.z == 0 %}
        RESPOND TYPE=error MSG="Nothing to save; the session adjustment is zero."
    {% else %}
        Z_OFFSET_APPLY_PROBE
        SAVE_CONFIG
    {% endif %}
```

With the part printing the first layer, keep sending `SOBE` until it looks good, then
`ZOFFSET_SALVAR`. Judging by the real result works better than judging by paper.

### Complete z-offset routine

Homes, heats the nozzle to soften anything stuck to it, tells it to cool while cleaning, and opens
manual adjustment at the temperature where the machine will print.

```ini
[gcode_macro EDDY_OFFSET_FULL]
description: Homes, cleans the nozzle and opens z-offset adjustment
variable_temp_limpeza: 200
variable_temp_offset: 150
variable_passadas: 20
gcode:
    {% set c = printer['gcode_macro EDDY_OFFSET_FULL'] %}
    G28
    M109 S{c.temp_limpeza}
    M104 S{c.temp_offset}
    M106 S255
    LIMPAR_BICO TEMP=0 PASSADAS={c.passadas}
    TEMPERATURE_WAIT SENSOR=extruder MAXIMUM={c.temp_offset + 2}
    M106 S0
    G90
    G0 Z10 F1200
    G0 X215 Y215 F6000
    G0 Z3 F600
    PROBE_CALIBRATE
```

Cleaning happens while the nozzle cools, with the fan on to speed it up. Measuring the offset with
the nozzle at one hundred and fifty degrees is intentional, because a hot nozzle is expanded, and
that is how it will be while printing.

### Keeping the bed warm between prints

This machine's bed is slow to heat. Keeping it warm while the printer is idle removes most of the
preheat wait from the next print.

```ini
[delayed_gcode MANTER_MESA_50]
initial_duration: 15
gcode:
    {% if printer.print_stats.state not in ["printing", "paused"] and printer.heater_bed.target < 50 %}
        M140 S50
    {% endif %}
    UPDATE_DELAYED_GCODE ID=MANTER_MESA_50 DURATION=60
```

It rearms itself every sixty seconds, does nothing while the printer is printing or paused, and never
lowers a target that is already above 50. A PETG print at 80 degrees stays at 80, and only returns to
50 when the print ends.

Two caveats. With this macro active, the bed never cools down by itself, because it always starts
heating back to 50. And a manual `M140 S0` only holds for one minute, until the macro's next cycle
turns the heater back on.

### PRINT_START, the print opening

The order of these steps matters, and each exists for a specific reason.

```ini
[gcode_macro PRINT_START]
gcode:
    {% set bed  = params.BED|default(printer.heater_bed.target)|float %}
    {% set extr = params.EXTRUDER|default(printer.extruder.target)|float %}
    G92 E0
    G90
    CLEAR_PAUSE
    M140 S{bed}
    {% if 'xyz' not in printer.toolhead.homed_axes %}
        G28
    {% endif %}
    SAVE_VARIABLE VARIABLE=was_interrupted VALUE=True
    LIMPAR_BICO
    M104 S{extr}
    M190 S{bed}
    G4 P5000
    M109 S{extr}
    G90
    G0 Z3 F600
    G28 Z
    BED_MESH_PROFILE LOAD=default
    PURGA_BAMBU Q=50
    LINHA_PURGA
    G92 E0
```

It tells the bed to heat without waiting, homes if needed, and cleans the nozzle at 150 degrees while
the bed is still rising. Nozzle cleaning and bed heating happen at the same time, and that is the
whole point of the design: it costs no extra time. Only after that come the final temperatures, the
soak, hot Z rehome, mesh loading, block purge, and purge line.

Two lessons are embedded here and deserve explanation.

The line `SAVE_VARIABLE VARIABLE=was_interrupted` must come **after** homing, never before. When it
was the first line of the macro, a homing failure left the printer marked as having an interrupted
print even though no print had started, and every next print attempt answered `SD busy`.

The explicit `G0 Z3` before `G28 Z` exists because whoever calls the macro already knows Z itself is
trustworthy at that point, something the `homing_override` from
[topic 11](#11-homing-and-the-first-home-ritual) never assumes by itself.

### Filament change

`M600` pauses the print and retracts 80 mm so the filament can be pulled out by hand, refusing the
retract below 170 degrees. After loading the new filament, `RESUME` runs `PURGA_BAMBU Q=100`, cleans
the nozzle on the pad, and returns to the part. There is no purge line on the way back; it only runs
at the start of the print.

It is worth recording what this routine replaced: a blind `G1 E100 F200` executed wherever the
carriage was stopped, dumping 100 mm of filament on top of the part and shaking the carriage in X
while trying to clean.

### Start gcode in OrcaSlicer

The whole print opening lives in the `PRINT_START` macro, so the slicer only needs to pass the two
temperatures. In OrcaSlicer, the field is in Machine, then Custom G-code, then Start G-code.

```
;ELEGOO NEPTUNE 4 MAX 0.6
M220 S100
M221 S100
G90
M82
PRINT_START BED=[bed_temperature_initial_layer_single] EXTRUDER=[nozzle_temperature_initial_layer]
```

Do not leave any `M190` or `M109` before that call, because that destroys the overlap between nozzle
cleaning and bed heating that `PRINT_START` was designed to do. And turn off all slicer purging, both
purge line and purge tower, or the printer purges twice.

The placeholders above use Orca and Prusa style. In Cura, the equivalent is
`{material_bed_temperature_layer_0}` and `{material_print_temperature_layer_0}`.

---

## 14. How to measure whether the calibration came out good

At the end of `PROBE_EDDY_CURRENT_CALIBRATE`, Klipper reports the standard deviation.

```
probe_eddy_current: stddev=67.901 in 2482 queries
```

That number by itself does not say much, because it is in hertz. To know what it means as distance,
take the table saved at the end of `printer.cfg` and see how many hertz correspond to one millimeter
at the height where the trigger happens.

On mine, between 1.5 and 2.5 mm, the curve moves 23422 hertz per millimeter.

```
67.9 divided by 23422 = 0.0029 mm
```

About three microns of repeatability at the trigger height, which is better than any contact probe I
have used.

Also check two properties of the table.

It needs to be **monotonic**, with frequency falling continuously as height rises, without any
inversion. If there is an inversion, the drive current is wrong and you go back to
[topic 9](#9-the-drive-current).

And sensitivity **falls as height rises**. On mine, 47672 hertz per millimeter near the bed against
12849 at the top of the range. That is not a defect; it is the nature of the sensor, and it explains
why it turns into an error when you try to use it from far away.

---

## 15. Symptom table

Always start with the first line of this table. Wrong `reg_drive_current` is the most common cause of
`Eddy current sensor error` on this machine, and testing it costs one command that does not move
anything.

| Symptom | Likely cause | Where to look |
|---|---|---|
| **`Eddy current sensor error`, at any height, even inside the calibrated range** | **Wrong `reg_drive_current`. Test first, before changing any height** | [Topic 9](#9-the-drive-current) |
| Homes XY, returns to the middle, does not descend and errors | False home at boot leaving Z high | [Trap 1](#trap-1-the-printer-declares-itself-zeroed-at-boot) |
| Descends, touches, and only then errors | `homing_retract_dist` too large | [Trap 3](#trap-3-the-retract-between-the-two-homing-passes) |
| Every Z movement descends more than commanded | Old `SET_GCODE_OFFSET` active | [Trap 2](#trap-2-an-old-z-compensation-applied-blindly) |
| `SAVE_CONFIG` refuses with "conflicts with included value" | `z_offset` written in an included file | [Trap 4](#trap-4-z_offset-written-by-hand-locks-save_config) |
| Second `PROBE` sample fails | `sample_retract_dist` overflowing the range | [Topic 7](#7-the-calculations-that-prevent-sensor-errors) |
| Error during the mesh, between points | `horizontal_move_z` overflowing the range | [Topic 7](#7-the-calculations-that-prevent-sensor-errors) |
| First layer crooked on only one side | Wrong `y_offset` or assumed zero | [Topic 5](#5-the-three-mounting-measurements) |
| Trigger at the wrong height after changing current | Table not redone | [Topic 8](#8-the-calibration-order) |
| Endstop reading triggered with the nozzle in the air | Removed probe pin floating high | [Topic 4](#4-what-the-eddy-does-and-does-not-do) |
| Eddy does not appear on the computer for flashing | BOOT button was not pressed before USB | [Topic 3](#3-how-the-eddy-appears-on-the-computer) |

### Two operation details

`FIRMWARE_RESTART` does not always reload the configuration. When you suspect that, force it through
the service and confirm by reading back what was loaded.

```bash
curl -s -X POST "http://SEU_IP/machine/services/restart?service=klipper"
```

If you keep the bed heated while idle, turn the heater off a few seconds before restarting the
service. Restarting with an active heater drops the MCU with
`Scheduled digital out event will exceed max_duration`. The shutdown cuts the heater, so there is no
risk, but you do need to turn it back on.

---

## License and warranty

No warranty. Changing probes carries a risk of driving the nozzle into the sheet, and you are the one
next to the printer. Go slowly, watch the nozzle, and stop when something looks wrong.

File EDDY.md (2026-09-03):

# BTT Eddy Duo na Elegoo Neptune 4 Max

Autor [@Igor3DPrint](https://instagram.com/igor3dprint)

> **Este guia usa o driver que vem no Klipper (`probe_eddy_current`), e continua valendo — é por aqui
> que se começa.** Duas coisas mudaram na máquina de referência depois que ele foi escrito, em
> 03/09/2026, e é bom você saber antes de ler:
>
> - Ela migrou para o **[eddy-ng](EDDY-NG.md)**, onde o Z-offset se mede sozinho a cada impressão.
>   Se o seu objetivo final é parar de calibrar Z, instale primeiro seguindo este documento e depois
>   vá para o [EDDY-NG.md](EDDY-NG.md).
> - A **borracha de limpeza foi removida** da máquina. As macros de limpeza de bico citadas mais
>   adiante (`LIMPAR_BICO`, `PURGA_BAMBU`, `EDDY_OFFSET_FULL`) ainda existem na configuração, mas não
>   são mais chamadas por nada. Não são erro; são histórico.

Este guia cobre a instalação da sonda BTT Eddy Duo na Neptune 4 Max rodando o Klipper moderno. Está
escrito na ordem em que as coisas acontecem, com os números que eu medi na minha máquina e os erros
que eu cometi antes de chegar neles.

Um resumo antes de tudo. O parâmetro que mais me atrasou foi a corrente de excitação da bobina, o
`reg_drive_current`. Com ele errado o sensor acusa falha mesmo com o bico na distância certa, e a
mensagem de erro aponta para o lugar errado. Está no [tópico 9](#9-a-corrente-de-excitação).

> Viu `Eddy current sensor error`? Rode `LDC_CALIBRATE_DRIVE_CURRENT CHIP=btt_eddy` antes de mexer em
> qualquer altura. O comando não move a máquina, então é seguro rodar a qualquer momento, e essa é a
> causa mais comum desse erro nesta máquina. Detalhe completo no [tópico 9](#9-a-corrente-de-excitação).

---

## Tópicos

1. [Hardware que eu usei](#1-hardware-que-eu-usei)
2. [Peça impressa](#2-peça-impressa)
3. [Como o Eddy aparece no computador](#3-como-o-eddy-aparece-no-computador)
4. [O que o Eddy faz e o que ele não faz](#4-o-que-o-eddy-faz-e-o-que-ele-não-faz)
5. [As três medidas da montagem](#5-as-três-medidas-da-montagem)
6. [A configuração base](#6-a-configuração-base)
7. [As contas que evitam erro de sensor](#7-as-contas-que-evitam-erro-de-sensor)
8. [A ordem da calibração](#8-a-ordem-da-calibração)
9. [A corrente de excitação](#9-a-corrente-de-excitação)
10. [Quatro armadilhas da Neptune 4 Max](#10-quatro-armadilhas-da-neptune-4-max)
11. [O homing e o ritual do primeiro home](#11-o-homing-e-o-ritual-do-primeiro-home)
12. [A malha densa](#12-a-malha-densa)
13. [Macros que eu uso no dia a dia](#13-macros-que-eu-uso-no-dia-a-dia)
14. [Como medir se a calibração ficou boa](#14-como-medir-se-a-calibração-ficou-boa)
15. [Tabela de sintomas](#15-tabela-de-sintomas)

---

## 1. Hardware que eu usei

Sonda **BTT Eddy Duo**, da BigTreeTech. A versão Duo se conecta por **USB**, direto na placa da
impressora ou no host. Não precisa de fio de dados ligado na placa mãe da Neptune, o que simplifica
bastante a instalação.

Ela aparece no Klipper como um MCU separado, com serial próprio.

```ini
[mcu eddy]
serial: /dev/serial/by-id/usb-Klipper_rp2040_SEU_ID_AQUI-if00
```

Para descobrir o seu ID, com a sonda plugada, rode dentro da impressora.

```bash
ls /dev/serial/by-id/
```

---

## 2. Peça impressa

O suporte que prende o Eddy no carro do extrusor da Neptune 4, o único STL necessário para esta
montagem.

https://www.printables.com/model/928061-neptune-4-btt-eddy-adapter

Imprima em **ABS ou ASA**. A peça fica perto do bico quente e sobre a mesa aquecida, e o PLA amolece
e deforma nessa faixa de temperatura, o que tira a precisão da geometria que segura a sonda. PETG é
um meio termo e ainda flui sob calor sustentado.

Tem duas variantes no modelo, uma reta e uma a noventa graus. Eu imprimi e usei a reta. Escolha
conforme a folga que sobrar no seu carro, porque a variante muda a posição do adaptador e junto com
ela a altura de montagem da bobina, e essa altura entra em todas as contas do
[tópico 7](#7-as-contas-que-evitam-erro-de-sensor). Meça a sua altura depois de montar, não copie a
minha.

Leva **2 porcas de embutir M3** (heat-set insert), fundidas com ferro de solda.

---

## 3. Como o Eddy aparece no computador

Este ponto merece destaque porque é onde muita gente trava antes mesmo de começar.

O **botão de BOOT do Eddy Duo fica na parte de cima da placa**. Ele não aparece sozinho no
computador quando você só liga o cabo. A sequência que funciona é a seguinte.

1. Com o cabo USB desconectado, pressione e segure o botão de BOOT
2. Sem soltar o botão, ligue o cabo USB no computador
3. Solte o botão

Sequência do botão de BOOT do Eddy Duo: USB desconectado, segurar o botão, ligar o USB, soltar o botão

Agora ele aparece, e você consegue gravar o firmware do Klipper nele.

Se você ligar o USB primeiro e só depois apertar o botão, ele não entra em modo de gravação. Foi o
que aconteceu comigo na primeira tentativa, e passei um tempo achando que a placa estava com
defeito.

Depois de gravado, ele passa a aparecer normalmente em `/dev/serial/by-id/` toda vez que a
impressora liga, sem precisar de botão nenhum.

---

## 4. O que o Eddy faz e o que ele não faz

O Eddy mede distância pela corrente parasita induzida numa bobina. Ele lê rápido, repete bem, e não
encosta em nada.

A limitação que quase ninguém avisa é o alcance. Ele enxerga **apenas os últimos milímetros**. Na
minha máquina a faixa calibrada vai de 0,05 mm até 4,05 mm. Acima disso o chip não vê a mesa, liga os
bits de erro e o Klipper aborta.

Daí sai a frase que resume o guia inteiro.

> O Eddy não serve sozinho como fim de curso de Z.

Um fim de curso mecânico dispara de qualquer altura. O Eddy não dispara, porque de longe não existe
leitura nenhuma para comparar.

Na Neptune 4 Max isso pesa, porque o `[stepper_z]` de fábrica usa
`endstop_pin: probe:z_virtual_endstop`, ou seja, a sonda é a única referência de Z que a máquina
tem. Se você remover a sonda original ao instalar o Eddy, como eu removi, cria um ciclo. Para homear
o bico precisa estar perto, e para saber que está perto o Z precisa estar homeado.

O [tópico 11](#11-o-homing-e-o-ritual-do-primeiro-home) mostra como quebrar esse ciclo. Se der para
manter a sonda original instalada em paralelo, mantenha, e você pula aquele tópico inteiro.

Um detalhe que me enganou. Depois de remover a sonda antiga, o pino dela continua na placa e
continua sendo lido. Entrada com resistor de pull-up e nada plugado flutua em nível alto, o que faz o
Klipper acreditar que existe um fim de curso acionado. Não confie no que o pino informa, confie no
que está parafusado na máquina.

> **Não tente usar o pino da sonda removida como fim de curso.** Eu tentei aqui, apontando o
> `[stepper_z]` para o pino da sonda antiga com a ponta vazia. O eixo desceu e não parou, porque o
> pino em nível alto por pull-up nunca muda de estado, e foi preciso cortar a energia da impressora.
> Só volte a usar esse pino depois de ter um sensor de verdade parafusado na ponta dele.

---

## 5. As três medidas da montagem

Depois de parafusar o adaptador você precisa de três números. Errar qualquer um deles faz a malha
inteira medir o lugar errado.

### Altura da bobina

Encoste o bico na mesa e meça quanto a face da bobina fica acima da ponta do bico. Na minha ficou
**0,94 mm**. A BigTreeTech recomenda entre dois e três milímetros.

Eu fiquei mais baixo por escolha, e isso reduz a folga de manobra. Com 0,94 mm, quando o bico está a
três milímetros da mesa a bobina está a 3,94 mm, quase no limite dos 4,05 mm que ela enxerga.

Guarde esse número, porque ele entra em todas as contas do próximo tópico.

```
altura da bobina = altura do bico + altura de montagem
```

Vista lateral da bobina, da mesa e da faixa de leitura de 0,05 a 4,05 mm

A imagem mostra por que um mergulho que começa acima dessa faixa falha já na primeira amostra, o chip
não tem leitura nenhuma para comparar naquela altura.

### Deslocamento em X

Meça do centro do bico ao centro da bobina, na horizontal. Na minha deu **33,34 mm**.

O sinal confunde. A regra que eu uso é olhar o `[stepper_x]` no `printer.cfg`. Com
`position_endstop: 0` e `homing_positive_dir: false`, o fim de curso fica no lado X igual a zero, ou
seja, na esquerda. Se a bobina está do mesmo lado do fim de curso, ela fica à esquerda do bico, e o
`x_offset` é **negativo**.

No meu caso ficou `x_offset: -33.34`.

### Deslocamento em Y

Este é o que quase todo mundo assume como zero. Eu assumi, e depois refiz uma malha inteira por
causa disso. Meça.

Na minha o Eddy fica **atrás** do bico e deu **20 mm**. Atrás quer dizer que a bobina cobre um ponto
do prato com Y maior que o do bico, então o `y_offset` é **positivo**.

No meu caso ficou `y_offset: 20`.

Rodei uma malha completa com `y_offset` em zero quando o certo era vinte. Cada ponto foi medido vinte
milímetros fora do lugar. A malha parecia normal na tela e estava errada inteira.

---

## 6. A configuração base

Eu mantenho o Eddy num arquivo separado chamado `eddy.cfg`, com um `[include eddy.cfg]` no
`printer.cfg`. Fica mais fácil de comparar e de reverter.

```ini
[mcu eddy]
serial: /dev/serial/by-id/usb-Klipper_rp2040_SEU_ID_AQUI-if00

[probe_eddy_current btt_eddy]
sensor_type: ldc1612
i2c_mcu: eddy
i2c_bus: i2c0f
x_offset: -33.34
y_offset: 20
speed: 5.0
samples: 2
samples_result: median
sample_retract_dist: 1.0

[bed_mesh]
speed: 200
horizontal_move_z: 2.5
mesh_min: 20,25
mesh_max: 390,410
probe_count: 6,6
algorithm: bicubic
bicubic_tension: 0.2
mesh_pps: 2, 2
fade_start: 5.0
fade_end: 30.0
```

Repare que **não existe `z_offset` nesse bloco**, e isso é de propósito. O motivo está na
[armadilha 4](#armadilha-4-o-z_offset-escrito-à-mão-trava-o-save_config).

### Por que o mesh_max não cobre o prato inteiro

O prato tem 420 mm, mas a área que dá para medir é menor, e a culpa é da geometria da sonda. O
Klipper calcula assim.

```
posição do bico = ponto da malha menos o offset do eixo
```

Com `x_offset: -33.34`, o bico precisa ir para `ponto + 33,34`. O `position_max` do X é 430,1, então
o ponto mais à direita que dá para medir fica por volta de 396. Eu uso 390 para sobrar margem, o que
leva o bico a 423,34.

Com `y_offset: 20`, o bico vai para `ponto - 20`. Um `mesh_min` em Y de 25 leva o bico a 5, quase
encostado no batente da frente.

O limite inferior de X também tem motivo. Com `mesh_min` em X abaixo de 20, a bobina passaria por
cima da borracha de limpeza, que tem sete milímetros de altura, durante a varredura.

Vista de cima do prato, com a posição do bico contra a posição da bobina e a área da malha resultante

---

## 7. As contas que evitam erro de sensor

Três desigualdades. Chame de `F` o topo da faixa calibrada, que na minha máquina é 4,05, e de `M` a
altura de montagem da bobina, que na minha é 0,94.

```
z_offset + sample_retract_dist   <  F
horizontal_move_z + M            <  F
altura de início do mergulho + M <  F
```

Se qualquer uma estourar, o sensor vai acusar erro em algum ponto do ciclo, e o sintoma vai parecer
outra coisa completamente diferente.

### Primeira conta, o sample_retract_dist

Com `samples: 2` o Klipper sonda, sobe esse tanto e sonda de novo. O gatilho acontece com a bobina
lendo o valor do `z_offset`. Se o recuo for grande demais, a segunda sondagem começa fora da faixa.

O padrão de fábrica é 3,0. Com `z_offset` perto de 2,0 isso dá 5,0 e estoura. Eu uso **1,0**.

### Segunda conta, o horizontal_move_z

É a altura do bico durante a viagem entre pontos da malha. Some a altura de montagem para saber onde
a bobina fica.

O padrão de dez milímetros colocaria a bobina a 10,94 mm, cega. Eu uso **2,5**, que resulta em 3,44
mm.

### Terceira conta, a altura de início do mergulho

Quem define isso é o `z_hop` do `safe_z_home`, ou o seu `homing_override`. Com montagem de 0,94 mm,
começar o mergulho a três milímetros deixa a bobina em 3,94 mm, dentro da faixa mas com pouca folga.

---

## 8. A ordem da calibração

Esta é a parte que eu fiz na ordem errada e que me custou uma noite inteira.

1. Escrever a configuração base com os offsets medidos
2. Calibrar a corrente de excitação com `LDC_CALIBRATE_DRIVE_CURRENT CHIP=btt_eddy` e rodar
   `SAVE_CONFIG`
3. Só então construir a tabela com `PROBE_EDDY_CURRENT_CALIBRATE CHIP=btt_eddy` e rodar `SAVE_CONFIG`
4. Testar o homing
5. Depois disso, a malha

Nunca o contrário, e nunca só uma das duas calibrações.

A corrente de excitação define a amplitude do sinal, e mudar ela desloca todas as frequências. Se
você construir a tabela primeiro e mexer na corrente depois, a tabela perde a validade.

O pior é que ela não avisa. Ela passa a disparar o gatilho na altura errada, o que significa bico
contra a chapa.

> Mexeu no `reg_drive_current`, a tabela morreu. Refaça o `PROBE_EDDY_CURRENT_CALIBRATE` antes de
> mandar qualquer `G28`.

---

## 9. A corrente de excitação

**Este é o parâmetro que mais derruba gente nesta máquina.** Se você chegou aqui direto de um erro de
sensor, leia este tópico inteiro antes de mexer em qualquer altura, recuo ou offset.

O LDC1612 excita a bobina com uma corrente configurável chamada `reg_drive_current`, que é um número
inteiro de zero a trinta e um. Ela precisa estar casada com a sua bobina, a sua altura de montagem e
a sua mesa.

Corrente **alta demais** satura a amplitude. Corrente **baixa demais** apaga o sinal. Nos dois casos
o chip liga um bit de erro e o Klipper devolve isto.

```
Error during homing z: Eddy current sensor error
```

Aqui está a armadilha. Essa mensagem parece dizer que o sensor está longe da mesa, e não é isso que
ela informa. No meu caso o bico estava a dois milímetros, dentro da faixa, e o erro acontecia igual.
Passei horas mexendo em altura, em temperatura da mesa e em distância de recuo, quando o problema
era o ganho do sinal.

Se quiser confirmar na fonte, o erro nasce no firmware, em `src/sensor_ldc1612.c`.

```c
if (data > 0x0fffffff) {
    // Sensor reports an issue - cancel homing
    ld->homing_flags = 0;
    trsync_do_trigger(ld->ts, ld->error_reason);
    return;
}
```

Os quatro bits altos são os bits de erro do próprio chip. Repare que o teste vem **antes** de
qualquer movimento, então ele aborta na primeira amostra. É por isso que o sintoma aparece como
"não desce e já dá erro". E repare também que isso não tem relação com a tabela `calibrate`, porque é
hardware reclamando, não o Klipper comparando números.

### Como medir sem mover a máquina

Existe um comando que faz o próprio chip escolher o valor certo, na posição em que ele está, sem
mover nada.

```
LDC_CALIBRATE_DRIVE_CURRENT CHIP=btt_eddy
```

A resposta sai no console.

```
probe_eddy_current btt_eddy: reg_drive_current: 16
```

Compare com o que está na sua configuração. No meu caso estava dezoito e o chip queria dezesseis.
Dois pontos de diferença travavam tudo.

O número não é fixo para sempre. Depois de remontar a sonda e remedir `x_offset` e `y_offset`, rodei
o comando de novo e ele voltou a apontar dezoito. Trate qualquer valor deste guia como o retrato de
um instante, não como constante. Toda vez que a montagem física mudar, meça de novo antes de confiar
no número antigo, o seu ou o meu.

### Onde esse comando mora

Se você procurar esse comando dentro do `probe_eddy_current.py`, não acha, e é fácil concluir que o
seu fork do Klipper não tem. Ele fica no `ldc1612.py`, que é o driver do chip.

```bash
grep -n "LDC_CALIBRATE_DRIVE_CURRENT" ~/klipper*/klippy/extras/ldc1612.py
```

Eu quase abandonei essa linha de investigação porque procurei no arquivo errado.

### Depois de medir

Rode `SAVE_CONFIG`. A impressora reinicia com o valor novo. Em seguida refaça a tabela, como está no
[tópico 8](#8-a-ordem-da-calibração). Não pule essa parte.

---

## 10. Quatro armadilhas da Neptune 4 Max

Listadas na ordem em que apareceram aqui, porque uma escondia a outra. Se você tem
`Eddy current sensor error` e já conferiu a altura, muito provavelmente é uma destas.

### Armadilha 1, a impressora se declara zerada no boot

No `printer.cfg` e no `plr.cfg` da Neptune existe este bloco.

```ini
[delayed_gcode KINEMATIC_POSITION]
initial_duration: 3.0
gcode:
      SET_KINEMATIC_POSITION X=110
      SET_KINEMATIC_POSITION Y=110
      SET_KINEMATIC_POSITION Z=0
```

Poucos segundos depois de ligar, o Klipper passa a acreditar que o Z está em zero, com o bico
fisicamente a trinta milímetros da mesa. Quando você manda `G28`, o `safe_z_home` conclui que o Z já
está homeado, que zero é menor que o `z_hop`, e **sobe** o bico para "três", que na vida real são
trinta e três. A bobina não vê nada e aborta.

O sintoma é bem característico. Ele homeia X e Y, volta para o meio, não desce, e já dá o erro.

Comente o bloco inteiro nos dois arquivos. Ele aparece duplicado, e quem vale é o do `printer.cfg`,
porque vem depois na ordem de leitura. Comentar só um não resolve.

O mesmo bloco também é a causa raiz do Z-offset que parece ignorado nesta máquina, com a versão
completa da explicação em [Z-OFFSET.md](Z-OFFSET.md#2-a-impressora-se-declara-zerada-alguns-segundos-depois-de-ligar-sem-ter-homeado).

### Armadilha 2, uma compensação de Z antiga aplicada às cegas

Eu tinha isto no `printer.cfg`, de quando usava a sonda de contato.

```ini
[gcode_macro G28]
rename_existing: G28.1
gcode:
    G28.1 {rawparams}
    SET_GCODE_OFFSET Z=-1.95
```

Depois de trocar de sonda, isso continuou sendo aplicado. Todo `G0 Z` passou a descer 1,95 mm a mais
do que eu mandava. Foi assim que eu arrastei o bico na chapa enquanto tentava posicionar
manualmente.

Confira o valor ativo na sua máquina agora.

```bash
curl -s "http://SEU_IP/printer/objects/query?gcode_move" | grep -o '"homing_origin": \[[^]]*\]'
```

Se o terceiro número não for `0.0`, existe um deslocamento escondido comendo a sua descida. Zere isso
antes de mandar qualquer movimento manual em Z.

### Armadilha 3, o recuo entre as duas passadas do homing

O `[stepper_z]` vem com `homing_retract_dist: 5`.

O Klipper encosta no gatilho, sobe esse tanto, e faz uma segunda passada lenta para confirmar. Com o
gatilho a dois milímetros de leitura, subir cinco leva a bobina a sete, fora da faixa. A segunda
passada começa cega e o chip aborta.

O sintoma engana porque a **primeira passada funciona**. Você vê a máquina descer, encostar, e só
então dar erro. Parece problema de gatilho e é problema de recuo.

Eu uso **1,5**, que deixa a bobina em 3,5 mm.

### Armadilha 4, o z_offset escrito à mão trava o SAVE_CONFIG

Se você escrever `z_offset` no `eddy.cfg`, que é um arquivo incluído, todo `SAVE_CONFIG` depois de um
`PROBE_CALIBRATE` vai falhar com esta mensagem.

```
SAVE_CONFIG section 'probe_eddy_current btt_eddy' option 'z_offset' conflicts with included value
```

O Klipper não sobrescreve por autosave um valor que veio de um include. A calibração roda, mostra o
número novo, e não consegue gravar.

A solução é deixar o `z_offset` fora do `eddy.cfg` e permitir que ele viva no bloco autosave, no fim
do `printer.cfg`. Se você está migrando de uma configuração que já tinha o valor escrito à mão,
remova a linha do arquivo incluído e acrescente o valor no bloco autosave.

```
#*# [probe_eddy_current btt_eddy]
#*# z_offset = 0.300
#*# reg_drive_current = 18
```

---

## 11. O homing e o ritual do primeiro home

Se a sua sonda original foi removida, o primeiro `G28` depois de ligar não tem como funcionar
sozinho, porque não existe referência de Z e a bobina só enxerga quatro milímetros.

O ciclo sem sonda de contato, e como quebrá-lo

O que funciona, e é seguro, é homear X e Y primeiro e depois **descer olhando**.

```
G28 X Y
G0 X215 Y215 F6000
```

Agora desça o Z pelo painel, olhando o bico, até uns dois milímetros da mesa. Use passos de dez
apenas enquanto estiver claramente longe, depois um, depois zero vírgula um. Em seguida.

```
G28 Z
```

Feito isso o Z fica homeado, e a impressora funciona normalmente até você desligar.

> Nunca mande um `G0 Z` absoluto para uma altura calculada de cabeça enquanto o Z não for confiável.
> Foi exatamente assim que eu arrastei o bico. Passo pequeno, olho no bico, e pare se encostar.

### Separando a folga de viagem da altura de mergulho

Se você tem algo alto na mesa perto da origem, como a borracha de limpeza, o `z_hop` do
`safe_z_home` cria um impasse. Ele é ao mesmo tempo a folga da viagem até o fim de curso e a altura
de início do mergulho. Você precisa de folga alta para viajar e de altura baixa para sondar, e um
número só não resolve as duas coisas.

A saída é trocar o `safe_z_home` por um `homing_override`.

```ini
[homing_override]
axes: xyz
gcode:
    {% set tudo = 'X' not in params and 'Y' not in params and 'Z' not in params %}
    {% set z_tinha_referencia = 'z' in printer.toolhead.homed_axes %}
    {% if not z_tinha_referencia %}
        SET_KINEMATIC_POSITION Z=0
    {% endif %}
    G91
    G0 Z16 F600
    G90
    {% if tudo or 'X' in params %}
        G28 X
    {% endif %}
    {% if tudo or 'Y' in params %}
        G28 Y
    {% endif %}
    {% if tudo or 'Z' in params %}
        {% if not z_tinha_referencia %}
            { action_raise_error("Z sem referencia. O Eddy so enxerga ate 4mm, entao o mergulho as cegas nao funciona. X e Y ja estao homeados. Desca o bico no painel ate uns 2mm da mesa e rode G28 Z.") }
        {% endif %}
        G0 X239.25 Y194.55 F6000
        G91
        G0 Z-16 F600
        G90
        G28 Z
    {% endif %}
```

Ajuste o `G0 X239.25 Y194.55` para o ponto de sondagem da sua máquina.

Esta versão ganhou uma trava. Quando o Z não tem referência nenhuma, ela homeia X e Y normalmente e
**para**, com uma instrução escrita em vez de mergulhar às cegas. Isso transforma um
`Eddy current sensor error` confuso numa mensagem que diz o que fazer, descer o bico no painel até
perto da mesa e rodar `G28 Z` na mão, como descrito no início deste tópico.

A lógica em português. Ele sobe dezesseis milímetros relativos, o que é seguro de qualquer altura,
inclusive com o Z virgem. Homeia X e Y com folga total sobre a borracha. Volta ao ponto de sondagem.
Desce os mesmos dezesseis milímetros relativos, devolvendo o bico exatamente à altura de onde saiu.
E aí sonda.

Repare que **não existe descida para altura absoluta** aqui dentro. Eu cheguei a escrever uma versão
que descia para Z igual a três quando o Klipper achava o Z conhecido, e isso é perigoso, porque uma
referência declarada na mão com `SET_KINEMATIC_POSITION` também conta como conhecida. A descida
viraria um mergulho de dezenas de milímetros contra a mesa.

Quem sabe que o próprio Z é confiável, como uma macro de início de impressão que acabou de homear,
se posiciona sozinho antes de chamar `G28 Z`.

O `safe_z_home` e o `homing_override` não podem coexistir. Comente um para usar o outro.

---

## 12. A malha densa

Sonda de contato leva quase um segundo por ponto. O Eddy varre em movimento contínuo, e é aqui que
ele paga o investimento. Dá para medir milhares de pontos no tempo em que a mesa estabiliza.

```ini
[gcode_macro EDDY_MALHA]
description: Malha densa de toda a area util. Ex, EDDY_MALHA BED=50 SOAK=300
variable_pontos: 70
gcode:
    {% set c = printer['gcode_macro EDDY_MALHA'] %}
    {% set bed = params.BED|default(50)|float %}
    {% set soak = params.SOAK|default(300)|int %}
    {% set n = params.PONTOS|default(c.pontos)|int %}
    M117 Aquecendo a mesa
    M140 S{bed}
    TEMPERATURE_WAIT SENSOR=heater_bed MINIMUM={bed - 1} MAXIMUM={bed + 1}
    M117 Soak
    G4 P{soak * 1000}
    M117 Homeando
    G28
    BED_MESH_CLEAR
    M117 Varrendo a mesa
    _BED_MESH_CALIBRATE METHOD=rapid_scan HORIZONTAL_MOVE_Z=2.5 PROBE_COUNT={n},{n} MESH_PPS=0 SCAN_SPEED=200
    M400
    RESPOND TYPE=command MSG="Malha pronta. Rode SAVE_CONFIG para gravar."
```

Uso normal.

```
EDDY_MALHA
SAVE_CONFIG
```

São 4900 pontos numa área de 370 por 385 milímetros, cerca de 5,3 mm de espaçamento. Contra os seis
por seis de fábrica, que dão setenta e três milímetros de espaçamento, a diferença é grande.

Três observações que valem para qualquer máquina.

O `rapid_scan` só é liberado quando a sonda é do tipo `probe_eddy_current`. Com sonda de contato o
Klipper cai no método normal sem avisar.

O `HORIZONTAL_MOVE_Z` é a altura do **bico** durante a varredura, não da bobina. Refaça a conta do
[tópico 7](#7-as-contas-que-evitam-erro-de-sensor) com a sua altura de montagem.

O tempo da rotina é quase todo soak, e o soak é o que faz a malha valer alguma coisa. Mesa fria mede
uma superfície, mesa estabilizada mede outra. Meia hora de rotina com cinco minutos de varredura é
tempo bem gasto.

---

## 13. Macros que eu uso no dia a dia

### Limpeza do bico na borracha

Passa o bico na almofada de silicone. Aceita parâmetros para reaproveitar em outros contextos.

```ini
[gcode_macro LIMPAR_BICO]
description: Limpa o bico na borracha
variable_x: 2.5
variable_y_ini: 5
variable_y_fim: 30
variable_z: 6.0
variable_passadas: 10
variable_temp: 150
gcode:
    {% set c = printer['gcode_macro LIMPAR_BICO'] %}
    {% set t = params.TEMP|default(c.temp)|float %}
    {% set n = params.PASSADAS|default(c.passadas)|int %}
    {% if 'xyz' not in printer.toolhead.homed_axes %}
        { action_raise_error("LIMPAR_BICO, eixos nao homeados") }
    {% endif %}
    {% if t > 0 %}
        M109 S{t}
    {% endif %}
    G90
    G0 Z{c.z + 6} F1200
    G0 X{c.x} Y{c.y_ini} F6000
    G0 Z{c.z} F600
    {% for i in range(n) %}
        G0 Y{c.y_fim} F6000
        G0 Y{c.y_ini} F6000
    {% endfor %}
    G0 Z{c.z + 10} F1200
```

Com `TEMP=0` ela não mexe na temperatura, o que permite chamar no meio de uma impressão.

O `variable_z` fica um milímetro abaixo da altura da borracha, o que dá a interferência que faz a
raspagem acontecer. Com borracha de sete milímetros eu uso seis.

### Purga em bloco no canto morto

Solta o filamento velho num canto e depois limpa o bico. É a ideia do coletor da Bambu adaptada.

```ini
[gcode_macro PURGA_BAMBU]
description: Purga em bloco no canto e limpa o bico. Ex, PURGA_BAMBU Q=50
variable_x: 0
variable_y: 45
variable_z: 15
variable_quantidade: 50
variable_velocidade: 150
variable_altura_segura: 15
gcode:
    {% set c = printer['gcode_macro PURGA_BAMBU'] %}
    {% set q = params.Q|default(c.quantidade)|float %}
    {% if 'xyz' not in printer.toolhead.homed_axes %}
        { action_raise_error("PURGA_BAMBU, eixos nao homeados") }
    {% endif %}
    {% if printer.extruder.temperature < 170 %}
        { action_raise_error("PURGA_BAMBU, bico frio demais para extrudar") }
    {% endif %}
    SAVE_GCODE_STATE NAME=purga_bambu
    G90
    G0 Z{c.altura_segura} F1200
    G0 X{c.x} Y{c.y} F6000
    G0 Z{c.z} F600
    M83
    G1 E{q} F{c.velocidade}
    G1 E-1.5 F2100
    G4 P1500
    G0 Z{c.altura_segura} F1200
    LIMPAR_BICO TEMP=0 PASSADAS=4
    G92 E0
    RESTORE_GCODE_STATE NAME=purga_bambu MOVE=1 MOVE_SPEED=200
```

A altura de purga muda bastante o resultado. A dois milímetros o material forma uma bolota grudada na
chapa. A quinze milímetros ele sai em fio e quase não encosta, que é o comportamento parecido com o
da Bambu. Eu uso quinze.

O volume eu tirei do próprio gcode inicial da Bambu Lab A1, que executa `G1 E50 F200`. Ela repete
esse bloco duas vezes quando está trocando material no AMS. Sem troca de cor, um bloco basta.

### Linha de purga na faixa morta

A purga em bloco sozinha não é suficiente para primar o bico para a primeira camada, então eu somei
uma linha de purga na faixa que a malha não cobre.

```ini
[gcode_macro LINHA_PURGA]
description: Linha de purga na faixa morta do lado esquerdo da mesa
variable_x_ida: 2.5
variable_x_volta: 3.1
variable_y_ini: 60
variable_y_fim: 300
variable_z: 0.4
variable_extrusao: 52
gcode:
    {% set c = printer['gcode_macro LINHA_PURGA'] %}
    G90
    M83
    G0 X{c.x_ida} Y{c.y_ini} Z{c.z} F6000
    G1 Y{c.y_fim} E{c.extrusao} F1200
    G0 X{c.x_volta}
    G1 Y{c.y_ini} E{c.extrusao} F1200
    G92 E0
```

Ela roda em X2,5, com a passada de volta em X3,1, de Y60 a Y300, na altura de 0,4 mm, com E52 por
passada. Isso é o dobro do fluxo normal, de propósito.

A posição não é acidente. O `mesh_min` em X é 20, então tudo abaixo disso já está fora da malha. A
faixa começa em Y60, vinte e cinco milímetros depois do fim da borracha de limpeza, que ocupa até
Y35.

### Ajuste de z-offset ao vivo

O `z_offset` da sonda tem sinal invertido em relação à intuição. Valor maior aproxima o bico da mesa.
Eu errei essa direção na primeira vez e quase bati o bico, então embrulhei em macros cujo nome
descreve o que acontece com o bico.

```ini
[gcode_macro SOBE]
description: Afasta o bico da mesa. Ex, SOBE P=0.05
gcode:
    {% set p = params.P|default(0.02)|float %}
    {% set m = 1 if 'z' in printer.toolhead.homed_axes else 0 %}
    SET_GCODE_OFFSET Z_ADJUST={p} MOVE={m}

[gcode_macro DESCE]
description: Aproxima o bico da mesa. Ex, DESCE P=0.05
gcode:
    {% set p = params.P|default(0.02)|float %}
    {% set m = 1 if 'z' in printer.toolhead.homed_axes else 0 %}
    SET_GCODE_OFFSET Z_ADJUST=-{p} MOVE={m}

[gcode_macro ZOFFSET_SALVAR]
description: Grava o ajuste da sessao no z_offset da sonda e reinicia
gcode:
    {% if printer.gcode_move.homing_origin.z == 0 %}
        RESPOND TYPE=error MSG="Nada para gravar, o ajuste da sessao esta zerado."
    {% else %}
        Z_OFFSET_APPLY_PROBE
        SAVE_CONFIG
    {% endif %}
```

Com a peça imprimindo a primeira camada, vá dando `SOBE` até ficar boa, depois `ZOFFSET_SALVAR`.
Julgar pelo resultado real funciona melhor que julgar pelo papel.

### Rotina completa de z-offset

Homeia, aquece o bico para amolecer o que estiver grudado, manda esfriar enquanto limpa, e abre o
ajuste manual na temperatura em que a máquina vai imprimir.

```ini
[gcode_macro EDDY_OFFSET_FULL]
description: Homeia, limpa o bico e abre o ajuste de z-offset
variable_temp_limpeza: 200
variable_temp_offset: 150
variable_passadas: 20
gcode:
    {% set c = printer['gcode_macro EDDY_OFFSET_FULL'] %}
    G28
    M109 S{c.temp_limpeza}
    M104 S{c.temp_offset}
    M106 S255
    LIMPAR_BICO TEMP=0 PASSADAS={c.passadas}
    TEMPERATURE_WAIT SENSOR=extruder MAXIMUM={c.temp_offset + 2}
    M106 S0
    G90
    G0 Z10 F1200
    G0 X215 Y215 F6000
    G0 Z3 F600
    PROBE_CALIBRATE
```

A limpeza acontece enquanto o bico esfria, com a ventoinha ligada para acelerar. Medir o offset com o
bico a cento e cinquenta graus é proposital, porque bico quente está dilatado, e é assim que ele vai
estar imprimindo.

### Manter a mesa aquecida entre impressões

A mesa desta máquina é lenta para esquentar. Mantê-la morna enquanto a impressora está parada tira a
maior parte da espera de pré-aquecimento da impressão seguinte.

```ini
[delayed_gcode MANTER_MESA_50]
initial_duration: 15
gcode:
    {% if printer.print_stats.state not in ["printing", "paused"] and printer.heater_bed.target < 50 %}
        M140 S50
    {% endif %}
    UPDATE_DELAYED_GCODE ID=MANTER_MESA_50 DURATION=60
```

Ela se rearma sozinha a cada sessenta segundos, não faz nada enquanto a impressora está imprimindo ou
pausada, e nunca reduz um alvo que já está acima de 50. Uma impressão em PETG a 80 graus continua a
80, e só volta para 50 quando a impressão termina.

Duas ressalvas. Com essa macro ativa, a mesa nunca esfria sozinha, porque ela sempre volta a subir
para 50. E um `M140 S0` manual só segura por um minuto, até o próximo ciclo da macro religar o
aquecedor.

### PRINT_START, a abertura da impressão

A ordem destes passos importa, e cada um existe por um motivo específico.

```ini
[gcode_macro PRINT_START]
gcode:
    {% set bed  = params.BED|default(printer.heater_bed.target)|float %}
    {% set extr = params.EXTRUDER|default(printer.extruder.target)|float %}
    G92 E0
    G90
    CLEAR_PAUSE
    M140 S{bed}
    {% if 'xyz' not in printer.toolhead.homed_axes %}
        G28
    {% endif %}
    SAVE_VARIABLE VARIABLE=was_interrupted VALUE=True
    LIMPAR_BICO
    M104 S{extr}
    M190 S{bed}
    G4 P5000
    M109 S{extr}
    G90
    G0 Z3 F600
    G28 Z
    BED_MESH_PROFILE LOAD=default
    PURGA_BAMBU Q=50
    LINHA_PURGA
    G92 E0
```

Manda a mesa esquentar sem esperar, homeia se precisar, e limpa o bico a 150 graus enquanto a mesa
ainda está subindo. A limpeza e o aquecimento da mesa acontecem ao mesmo tempo, e é esse o ponto
inteiro do desenho, não custa tempo extra. Só depois disso vêm as temperaturas finais, o soak, o
rehome de Z a quente, o carregamento da malha, a purga em bloco e a linha de purga.

Duas lições estão embutidas aqui e merecem explicação.

A linha `SAVE_VARIABLE VARIABLE=was_interrupted` precisa vir **depois** do homing, nunca antes.
Quando ela era a primeira linha da macro, uma falha no homing deixava a impressora marcada como tendo
uma impressão interrompida sem nenhuma impressão ter começado, e toda tentativa seguinte de imprimir
respondia `SD busy`.

O `G0 Z3` explícito antes do `G28 Z` existe porque quem chama a macro já sabe que o próprio Z é
confiável naquele ponto, algo que o `homing_override` do [tópico 11](#11-o-homing-e-o-ritual-do-primeiro-home)
nunca assume por conta própria.

### Troca de filamento

O `M600` pausa a impressão e retrai 80 mm para o filamento sair puxando à mão, recusando a retração
abaixo de 170 graus. Depois de carregar o filamento novo, o `RESUME` roda `PURGA_BAMBU Q=100`, limpa
o bico na borracha e volta para a peça. Não existe linha de purga na volta, ela só roda no início da
impressão.

Vale registrar o que essa rotina substituiu, um `G1 E100 F200` cego executado onde quer que o carro
estivesse parado, derrubando 100 mm de filamento em cima da peça e sacudindo o carro em X tentando
limpar.

### Gcode inicial no OrcaSlicer

Toda a abertura da impressão mora na macro `PRINT_START`, então o fatiador só precisa passar as duas
temperaturas. No OrcaSlicer, o campo fica em Machine, depois Custom G-code, depois Start G-code.

```
;ELEGOO NEPTUNE 4 MAX 0.6
M220 S100
M221 S100
G90
M82
PRINT_START BED=[bed_temperature_initial_layer_single] EXTRUDER=[nozzle_temperature_initial_layer]
```

Não deixe nenhum `M190` ou `M109` antes dessa chamada, porque isso destrói a sobreposição entre a
limpeza do bico e o aquecimento da mesa que o `PRINT_START` foi desenhado para fazer. E desligue toda
purga do fatiador, nem purga na régua nem torre de purga, senão a impressora purga duas vezes.

Os placeholders acima são do estilo Orca e Prusa. No Cura o equivalente é
`{material_bed_temperature_layer_0}` e `{material_print_temperature_layer_0}`.

---

## 14. Como medir se a calibração ficou boa

No fim do `PROBE_EDDY_CURRENT_CALIBRATE` o Klipper reporta o desvio padrão.

```
probe_eddy_current: stddev=67.901 in 2482 queries
```

Esse número sozinho não diz muita coisa, porque está em hertz. Para saber o que significa em
distância, pegue a tabela gravada no fim do `printer.cfg` e veja quantos hertz correspondem a um
milímetro na altura em que o gatilho acontece.

Na minha, entre 1,5 e 2,5 mm a curva anda 23422 hertz por milímetro.

```
67,9 dividido por 23422 = 0,0029 mm
```

Cerca de três micra de repetibilidade na altura de disparo, o que é melhor que qualquer sonda de
contato que eu já usei.

Confira também duas propriedades da tabela.

Ela precisa ser **monotônica**, com a frequência caindo de forma contínua conforme a altura sobe, sem
nenhuma inversão. Se houver inversão, a corrente de excitação está errada e você volta ao
[tópico 9](#9-a-corrente-de-excitação).

E a sensibilidade **cai conforme sobe**. Na minha, 47672 hertz por milímetro junto da mesa contra
12849 no topo da faixa. Isso não é defeito, é a natureza do sensor, e explica por que ele vira erro
quando você tenta usar de longe.

---

## 15. Tabela de sintomas

Comece sempre pela primeira linha desta tabela. `reg_drive_current` errado é a causa mais comum de
`Eddy current sensor error` nesta máquina, e o teste custa um comando que não move nada.

| Sintoma | Causa provável | Onde olhar |
|---|---|---|
| **`Eddy current sensor error`, em qualquer altura, mesmo dentro da faixa calibrada** | **`reg_drive_current` errado. Teste primeiro, antes de mexer em qualquer altura** | [Tópico 9](#9-a-corrente-de-excitação) |
| Homeia XY, volta pro meio, não desce e dá erro | Home falso no boot deixando o Z alto | [Armadilha 1](#armadilha-1-a-impressora-se-declara-zerada-no-boot) |
| Desce, encosta, e só então dá erro | `homing_retract_dist` grande demais | [Armadilha 3](#armadilha-3-o-recuo-entre-as-duas-passadas-do-homing) |
| Todo movimento em Z desce mais do que o comandado | `SET_GCODE_OFFSET` antigo ativo | [Armadilha 2](#armadilha-2-uma-compensação-de-z-antiga-aplicada-às-cegas) |
| `SAVE_CONFIG` recusa com "conflicts with included value" | `z_offset` escrito num arquivo incluído | [Armadilha 4](#armadilha-4-o-z_offset-escrito-à-mão-trava-o-save_config) |
| Segunda amostra do `PROBE` falha | `sample_retract_dist` estourando a faixa | [Tópico 7](#7-as-contas-que-evitam-erro-de-sensor) |
| Erro durante a malha, entre pontos | `horizontal_move_z` estourando a faixa | [Tópico 7](#7-as-contas-que-evitam-erro-de-sensor) |
| Primeira camada torta de um lado só | `y_offset` errado ou assumido zero | [Tópico 5](#5-as-três-medidas-da-montagem) |
| Gatilho na altura errada depois de mexer na corrente | Tabela não refeita | [Tópico 8](#8-a-ordem-da-calibração) |
| Fim de curso lendo acionado com o bico no ar | Pino de sonda removida flutuando alto | [Tópico 4](#4-o-que-o-eddy-faz-e-o-que-ele-não-faz) |
| O Eddy não aparece no computador para gravar | Botão de BOOT não foi pressionado antes do USB | [Tópico 3](#3-como-o-eddy-aparece-no-computador) |

### Dois detalhes de operação

O `FIRMWARE_RESTART` nem sempre recarrega a configuração. Quando desconfiar, force pelo serviço e
confira lendo de volta o que ficou carregado.

```bash
curl -s -X POST "http://SEU_IP/machine/services/restart?service=klipper"
```

Se você mantém a mesa aquecida parada, desligue o aquecedor alguns segundos antes de reiniciar o
serviço. Reiniciar com aquecedor ativo derruba o MCU com
`Scheduled digital out event will exceed max_duration`. O desligamento corta o aquecedor, então não
há risco, mas exige religar.

---

## Licença e garantia

Sem garantia. Mexer em sonda tem risco de bico contra a chapa, e quem está do lado da impressora é
você. Vá devagar, olhe o bico, e pare quando ficar estranho.

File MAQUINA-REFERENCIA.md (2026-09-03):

# A máquina de referência

Esta é a Neptune 4 Max em que este repositório foi escrito, descrita por inteiro: o hardware que
está montado nela, cada valor que está gravado na configuração, cada coisa que foi mudada e por quê,
e o que ainda está em aberto.

Serve para duas coisas.

Se você é humano, é o exemplo completo. Os outros documentos ensinam o procedimento; este mostra
uma máquina onde o procedimento já foi até o fim.

Se você é uma IA conduzindo alguém, é a sua referência trabalhada. Quando o usuário perguntar
"e quanto devo colocar aqui", você tem um caso real inteiro para explicar o raciocínio, com a conta
que justifica cada número. **Nenhum destes números deve ser copiado para outra impressora sem
medição.** Eles são o exemplo, não a resposta.

> Os endereços de rede abaixo são da rede local do autor. Troque pelo IP da impressora do usuário.

---

## ⚠️ Esta máquina mudou em 03/09/2026 — leia antes do resto

Ela saiu do driver `probe_eddy_current` e passou a usar o **[eddy-ng](EDDY-NG.md)**
(`probe_eddy_ng`). O que isso invalida, mais abaixo neste documento e no
[Z-OFFSET.md](Z-OFFSET.md):

- **Todo o problema do "Z-offset que não obedece" deixou de existir aqui.** O eddy-ng não usa
  `z_offset` nenhum: o zero é medido por *tap* a cada impressão. As causas continuam reais e valem
  para quem usa o driver padrão — só não se aplicam mais a esta máquina.
- **A borracha de limpeza foi removida fisicamente.** `LIMPAR_BICO`, `PURGA_BAMBU`, `LINHA_PURGA` e
  `EDDY_OFFSET_FULL` continuam escritas na configuração, mas **nada chama elas**. A purga agora é a
  `LINHA_KAMP`, uma linha só na frente da mesa.
- **O Klipper roda em Python 3.7.3** (`~/klippy-env-py3`). O ambiente Python 2 antigo continua no
  disco como caminho de volta.
- O firmware do Eddy foi recompilado localmente e tem o sensor `ldc1612_ng`.

Valores da calibração nova: `reg_drive_current 17` (homing), `tap_drive_current 18` (tap), tap
medido em **−0,050 mm com desvio padrão de 0,006 mm**, com a bobina montada a 0,94 mm do bico.

Os arquivos de configuração completos desta máquina, já sanitizados, estão em [config/](config/).

---

## Acesso

| Item | Valor |
|---|---|
| IP | SEU_IP |
| SSH | `ssh mks@SEU_IP`, sem senha, chave já autorizada |
| Interface | Fluidd |
| Klipper | fork sandmmakers, `sandmmakers-ElegooNeptune4Max-v1.2.3.4-v0.13.0-51-1`, rodando em **Python 3.7.3** |
| Sonda | **eddy-ng** (`probe_eddy_ng`), não mais `probe_eddy_current` |
| Config | `/home/mks/klipper_config/printer.cfg` mais `eddy.cfg`, `eddyng_macros.cfg` e `plr.cfg` |
| Fonte | `/home/mks/klipper.sandmmakers/` |
| Log | `/home/mks/klipper_logs/klippy.log` |

Leitura de estado sem tocar na máquina

```bash
curl -s "http://SEU_IP/printer/info"
curl -s "http://SEU_IP/printer/objects/query?configfile=settings"
curl -s "http://SEU_IP/printer/objects/query?toolhead&gcode_move&heater_bed&extruder"
curl -s "http://SEU_IP/server/files/config/printer.cfg"
curl -s "http://SEU_IP/server/gcode_store?count=30"
```

A resposta de um `POST /printer/gcode/script` não traz a saída do comando. Para ler o que o Klipper
respondeu, use o `gcode_store`.

---

## Hardware

Sonda **BTT Eddy Duo**, ligada por USB, montada com adaptador impresso. O botão de BOOT fica em cima
da placa, e para gravar firmware é preciso segurar o botão antes de plugar o USB.

A **sonda original de contato foi removida da cabeça**. O cabo dela continua ligado na placa, no pino
`PA11`, mas não existe sensor na ponta. O pino flutua em nível alto por causa do pull-up. Já foi
tentado usar `PA11` como fim de curso de Z em 2026-08-29 e o eixo desceu sem parar, sendo necessário
cortar a energia. Não repita isso sem reinstalar fisicamente um sensor.

Borracha de limpeza, almofada de silicone da Bambu Lab A1, montada em suporte impresso na região
X0 a X5 e Y0 a Y35, com sete milímetros de altura.

Guias de canto impressos para o prato magnético voltar sempre na mesma posição.

Adaptador do Eddy impresso, modelo de https://www.printables.com/model/928061-neptune-4-btt-eddy-adapter,
em ABS ou ASA — fica sobre a mesa aquecida e ao lado do hotend, e PLA deforma em serviço.

---

## Geometria medida

| Medida | Valor | Como foi obtida |
|---|---|---|
| Altura de montagem da bobina | 0,94 mm acima da ponta do bico | medida com o bico encostado na mesa |
| `x_offset` | -33,34 | paquímetro, bobina à esquerda do bico |
| `y_offset` | +20 | bobina atrás do bico |
| Faixa útil da bobina | 0,05 mm a 4,05 mm | tabela de calibração |

Regra que vale para toda conta neste documento

```
altura da bobina = altura do bico + 0,94
```

---

## Valores atuais (eddy-ng, desde 03/09/2026)

Esta máquina usa **[eddy-ng](EDDY-NG.md)** (`probe_eddy_ng`), não mais `probe_eddy_current`. Não
existe `z_offset`: o zero é medido por *tap* a cada impressão. Não rode
`PROBE_EDDY_CURRENT_CALIBRATE` nem `LDC_CALIBRATE_DRIVE_CURRENT` — são comandos do driver antigo.

```
probe_eddy_ng btt_eddy
  x_offset            -33.34
  y_offset            20.0
  reg_drive_current   17   (homing)
  tap_drive_current   18   (tap)
  tap                 -0,050 mm, desvio padrão 0,006 mm

bed_mesh
  mesh_min            20, 25
  mesh_max            390, 410
  horizontal_move_z   2.5

stepper_z
  endstop_pin         probe:z_virtual_endstop
  homing_retract_dist 1.5
```

Meça o seu — estes valores são desta máquina, não uma constante. Se você está usando o driver
padrão `probe_eddy_current` (ainda válido, veja [EDDY.md](EDDY.md)), ele usa `z_offset` e
`reg_drive_current`, que aqui não existem mais.

---

## O que foi alterado nesta sessão

### Correções que destravaram o homing

`[delayed_gcode KINEMATIC_POSITION]` desativado no `printer.cfg` e no `plr.cfg`. Ele declarava o Z
em zero poucos segundos depois de ligar, com o bico a trinta milímetros da mesa, e fazia o
`safe_z_home` subir o bico achando que estava baixo.

`[gcode_macro G28]` com `SET_GCODE_OFFSET Z=-1.95` desativado. Era compensação medida para a sonda
física antiga e continuou sendo aplicada depois da troca. Todo movimento em Z descia 1,95 mm a mais
que o comandado, e foi a causa de um bico arrastado na chapa.

`homing_retract_dist` de 5 para 1,5 no `[stepper_z]`. Com 5 a bobina ia para sete milímetros na
segunda passada do homing e o chip abortava.

`reg_drive_current` de 18 para 16, medido por `LDC_CALIBRATE_DRIVE_CURRENT CHIP=btt_eddy`. Em
seguida a tabela foi refeita com `PROBE_EDDY_CURRENT_CALIBRATE`, obrigatório depois de mexer na
corrente.

Numa sessão posterior, depois de remedir `x_offset` e `y_offset`, o comando voltou a apontar 18, e o
`z_offset` mudou de 1,861 para 0,300 junto com a tabela nova. A lição não muda: sempre que a montagem
física mexer, rode `LDC_CALIBRATE_DRIVE_CURRENT` de novo antes de confiar no número antigo.

`sample_retract_dist` de 3,0 para 1,0 e `horizontal_move_z` de 10 para 2,5, ambos estouravam a faixa
do sensor.

`x_offset` corrigido de -32,33 para -33,34 e `y_offset` de 0 para 20. O `y_offset` estava assumido
como zero e nunca havia sido medido, o que deslocava a malha inteira em vinte milímetros.

`z_offset` retirado do `eddy.cfg` e movido para o bloco autosave. Enquanto estava no arquivo
incluído, todo `SAVE_CONFIG` depois de um `PROBE_CALIBRATE` falhava com
`conflicts with included value`.

### Troca do safe_z_home por homing_override

O `z_hop` fazia duas coisas incompatíveis ao mesmo tempo, a folga da viagem até X0 e Y0, onde está a
borracha de sete milímetros, e a altura de início do mergulho, que precisa caber em quatro
milímetros. O `homing_override` separa as duas. Ele sobe dezesseis milímetros relativos, homeia X e
Y, volta ao ponto de sondagem e desce os mesmos dezesseis, devolvendo o bico à altura de onde saiu.

Não existe descida para altura absoluta dentro dele, e isso é deliberado. Uma versão intermediária
descia para Z igual a três quando o Klipper achava o Z conhecido, e isso é perigoso porque uma
referência declarada com `SET_KINEMATIC_POSITION` também conta como conhecida.

Ele ganhou uma guarda. Quando o Z não tem referência real, homeia X e Y e para com uma mensagem
escrita em vez de mergulhar às cegas.

### Macros criadas

```
LIMPAR_BICO        limpa o bico na borracha, aceita TEMP e PASSADAS
PURGA_BAMBU        purga em bloco em X0 Y45 a 15mm de altura e limpa o bico, aceita Q
LINHA_PURGA        linha de purga na faixa morta da lateral esquerda, X2.5, Y60 a Y300
SOBE / DESCE       ajusta o bico ao vivo, 0.02mm por padrão, aceita P
ZOFFSET            mostra o valor gravado e o ajuste de sessão
ZOFFSET_SALVAR     grava o ajuste no z_offset da sonda e reinicia
EDDY_OFFSET_FULL   homeia, aquece a 200, limpa esfriando até 150, abre o PROBE_CALIBRATE
EDDY_MALHA         mesa a 50, soak de 300s, malha 70x70 por varredura a 200mm/s
MANTER_MESA_50     delayed_gcode, segura a mesa em 50 quando ociosa, re-arma a cada 60s
```

`PRINT_START` refeito. Liga a mesa sem esperar, homeia se precisar, limpa o bico a 150 enquanto a
mesa sobe, vai para as temperaturas finais, faz soak, re-homeia o Z a quente, carrega a malha, purga
em bloco e faz a linha de purga.

O `SAVE_VARIABLE was_interrupted` foi movido para depois do homing. Enquanto era a primeira linha da
macro, um `G28` que falhava deixava a impressora marcada como tendo impressão interrompida sem
impressão nenhuma, e toda tentativa seguinte devolvia `SD busy`.

`m600` pausa e recua 80 mm para a troca. O `RESUME` chama `PURGA_BAMBU Q=100`, limpa o bico e volta.
Antes ele fazia `G1 E100 F200` na posição em que a peça estava parada.

### Fluidd

As macros `EDDY_OFFSET_FULL` e `EDDY_MALHA` estão pintadas de verde. A cor vive no banco do
Moonraker, namespace `fluidd`, chave `macros.stored`, num array onde cada item tem `name` minúsculo e
`color` em hex.

### Orca Slicer

Perfil `Elegoo Neptune 4 Max (0.6 nozzle) PRINCIPAL`, em
`C:\Users\Igor\AppData\Roaming\OrcaSlicer\user\default\machine\`

O gcode inicial foi reduzido a isto, porque tudo passou para as macros

```
;ELEGOO NEPTUNE 4 MAX 0.6
M220 S100
M221 S100
G90
M82
PRINT_START BED=[bed_temperature_initial_layer_single] EXTRUDER=[nozzle_temperature_initial_layer]
```

O gcode antigo chamava `MALHA_ADAPTATIVA` e `LINE_PURGE`, que são do KAMP. O KAMP está desativado
desde 2026-08-28, então essas duas linhas já vinham falhando silenciosamente.

---

## O ritual do primeiro home

Depois de ligar ou reiniciar, o Z não tem referência e o `G28` não funciona sozinho.

```
G28 X Y
G0 X215 Y215 F6000
```

Descer o Z pelo painel até uns dois milímetros da mesa, olhando o bico. Depois

```
G28 Z
```

A partir daí o Z fica homeado até desligar.

Nunca mandar um `G0 Z` absoluto calculado de cabeça enquanto o Z não for confiável. Foi assim que o
bico foi arrastado na chapa.

---

## Decisão em aberto

O ritual existe porque a sonda de contato foi removida e o Eddy só enxerga quatro milímetros. Três
caminhos foram apresentados ao Igor e ele ainda não escolheu.

**Conviver com o ritual.** Trinta segundos por ligada, risco zero. É o estado atual.

**Reinstalar um sensor de contato no `PA11`**, que está livre e com cabo já na placa. O `G28` voltaria
a funcionar de qualquer altura e o Eddy ficaria só com a malha. É a correção de raiz.

**Salvar e restaurar a altura do Z entre reinicializações.** Funciona porque o fuso segura a posição
com o motor desligado, mas se o valor ficar errado alguma vez o `G28` mergulha contra uma referência
falsa, e isso não dá erro, dá bico na mesa. É a mesma família do defeito original desta máquina.

---

## Erros conhecidos e o que cada um significa

| Sintoma | Causa |
|---|---|
| Homeia XY, volta ao meio, não desce e dá erro | Mergulho começou fora dos 4 mm |
| Desce, encosta, e só então dá erro | `homing_retract_dist` grande demais |
| Erro com o bico a 2 mm da mesa | `reg_drive_current` errado |
| Todo Z desce mais que o comandado | `SET_GCODE_OFFSET` antigo ativo |
| `SAVE_CONFIG` recusa com `conflicts with included value` | valor escrito num arquivo incluído |
| `SD busy` ao tentar imprimir | `was_interrupted` marcado sem impressão em curso |
| `Missed scheduling of next digital out event` | reinício do serviço com aquecedor ligado |

O erro `Eddy current sensor error` vem de `src/sensor_ldc1612.c`, em `check_home`, no teste
`if (data > 0x0fffffff)`. São os bits de erro do próprio chip, testados antes de qualquer movimento,
por isso ele aborta na primeira amostra. Não tem relação com a tabela `calibrate`.

O comando que mede a corrente sem mover nada é `LDC_CALIBRATE_DRIVE_CURRENT CHIP=btt_eddy`, e ele
mora em `klippy/extras/ldc1612.py`, não em `probe_eddy_current.py`.

---

## Cuidados operacionais

O `FIRMWARE_RESTART` nem sempre recarrega a configuração. Quando desconfiar, force pelo serviço e
confirme lendo de volta o que ficou carregado.

```bash
curl -s -X POST "http://SEU_IP/machine/services/restart?service=klipper"
```

A mesa fica ligada em 50 graus quando ociosa. Desligue o aquecedor alguns segundos antes de
reiniciar o serviço, senão o MCU cai com `Scheduled digital out event will exceed max_duration`.

Backups no diretório de configuração, todos com data no nome

```
printer.cfg.bak-2026-08-29        eddy.cfg.bak-2026-08-28
printer.cfg.bak-2026-08-29c       eddy.cfg.bak-2026-08-29b
printer.cfg.bak-2026-08-29d       eddy.cfg.bak-zoff2
printer.cfg.bak-2026-08-29e       plr.cfg.bak-2026-08-29
printer.cfg.bak-purga             printer.cfg.bak-purga2
printer.cfg.bak-fixhome           printer.cfg.bak-macros2
printer.cfg.bak-zoff2             printer.cfg.bak-guard
```

---

## Pendências

A malha densa de 4900 pontos (setenta por setenta) já foi feita e salva como perfil padrão. O
`PRINT_START` carrega ela.

A [Decisão em aberto](#decisão-em-aberto) sobre reinstalar ou não um sensor de contato continua sem
resposta — a máquina convive com o ritual do primeiro home.

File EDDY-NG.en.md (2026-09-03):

# eddy-ng: the Z-offset that measures itself

This document picks up where [EDDY.md](EDDY.en.md) stops. There you install the BTT Eddy with the
driver that comes with Klipper. Here you swap that driver for **eddy-ng**, and the machine starts
finding the nozzle zero by itself, on every print, instead of you calibrating with paper and saving a
number.

Done and measured on my Neptune 4 Max on 03/09/2026. Like everything else in this repository: it
broke first, worked later, and the mistakes are written down with the fix.

> **Credit.** The modern Klipper on this machine is the work of
> [S&M Makers](https://github.com/sandmmakers/klipper). eddy-ng is by
> [vvuk](https://github.com/vvuk/eddy-ng). I only put the two together on this printer and wrote down
> the path.

---

## 1. Eddy and eddy-ng: what is the difference, in two sentences

**The BTT Eddy is the hardware**: a coil that measures how far away the bed is, without touching it.
That does not change.

**eddy-ng is alternate software for that same hardware.** Same sensor, same cable, same part on the
toolhead. What changes is the program inside Klipper that interprets what the coil reads.

### Why switch

Eddy and eddy-ng use the same hardware

Every eddy sensor has the same problem: **the reading changes as things heat up.** The hot bed and
the hot coil itself shift the measurement. It is not a defect; it is the physics of the inductive
principle.

The two pieces of software attack that problem in different ways:

| | Standard driver (`probe_eddy_current`) | eddy-ng (`probe_eddy_ng`) |
|---|---|---|
| How it finds the nozzle zero | You do the paper test once and save the number | The nozzle **touches the bed** and zero is measured right then |
| When that happens | Once, and it is supposed to hold forever | On every print |
| Thermal drift | Corrected by a compensation table that you calibrate | Not needed: the measurement is already done hot |
| Swapping nozzles | Recalibrate everything | Do nothing; the next tap finds it by itself |
| Printing ABS at 100 °C after PLA at 60 °C | Zero is wrong; you compensate by eye | Zero is correct for both |

That "the nozzle touches and measures" has a name: **tap**. That is the whole feature. If tap does
not work on your mount, switching drivers is not worth it; the standard driver already does the rest.

### And what does NOT change

- Bed scanning speed. `rapid_scan` already exists in the standard driver.
- The physical part, the adapter, the wiring.
- The fact that the Eddy only sees the last few millimeters. Everything from [EDDY.md](EDDY.en.md)
  still applies.

---

## 2. Three things I was told would block it, and did not

I almost did not do this installation because of three "blockers". **Two were false and the third
was badly stated.** If you read this somewhere, read this too:

**"Klipper mainline does not have the HC32F460 port, so migrating leaves the mainboard without
firmware."** False. The `src/hc32f460` directory exists in
[Klipper mainline](https://github.com/Klipper3d/klipper/tree/master/src). And it is a useless
discussion anyway, because:

**"You need to migrate to Klipper mainline."** You do not. eddy-ng installs **on top of the
S&M Makers fork**, without changing Klipper. The whole installation is three symbolic links and two
`sed` commands.

**"The coil needs to be ~2.95 mm from the nozzle or tap will not work."** Here is the correct version:
the eddy-ng wiki says tap is *sensitive* to that height. Mine is at **0.94 mm**, one third of the
recommended height, and **tap works**: three measurements gave -0.050 / -0.042 / -0.057 mm, with a
standard deviation of **0.006 mm**. Six microns.

The lesson is not "ignore the wiki". It is that **calibration answers this for you in 2 minutes**
(topic 6), and the real number is worth more than the prediction. Run it and see.

---

## 3. What you need before starting

- A BTT Eddy already installed and **working** with the standard driver. If you are not there yet,
  [EDDY.md](EDDY.en.md) is the path. Do not start here.
- SSH access to the printer.
- One quiet hour. There is a step that restarts Klipper with a different Python interpreter, and you
  want to be near the machine.
- No print running.

**There is a way back at every step**, and it is in topic 10. Nothing here is irreversible.

---

## 4. The recipe, in order

The migration order

### Step 0 - protect what you already have

```bash
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

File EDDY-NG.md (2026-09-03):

# eddy-ng: o Z-offset que se mede sozinho

Este documento continua de onde o [EDDY.md](EDDY.md) para. Lá você instala o BTT Eddy com o driver
que vem no Klipper. Aqui você troca esse driver pelo **eddy-ng**, e a máquina passa a descobrir o
zero do bico sozinha, a cada impressão, em vez de você calibrar com papel e guardar um número.

Feito e medido na minha Neptune 4 Max em 03/09/2026. Como todo o resto deste repositório: quebrou
primeiro, funcionou depois, e os erros estão escritos junto.
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

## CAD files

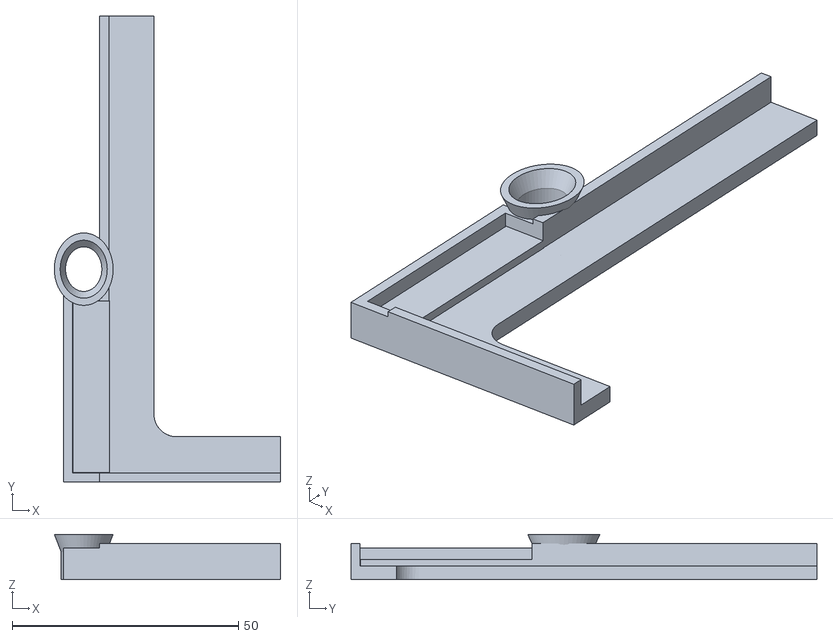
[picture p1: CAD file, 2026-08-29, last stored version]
stl/nozzle-cleaner-holder-improved-lifted-pad-n4.stl
50.0 x 102.9 x 10.0

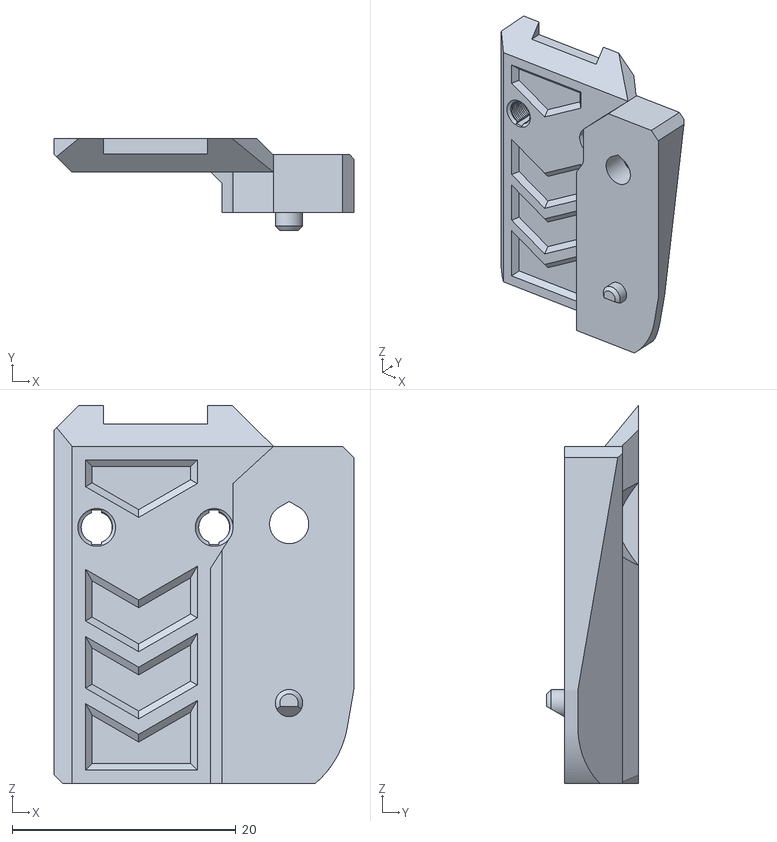
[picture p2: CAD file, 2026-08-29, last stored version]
stl/BTT-Eddy_Adapter_v05.stl
26.8 x 8.20 x 33.8

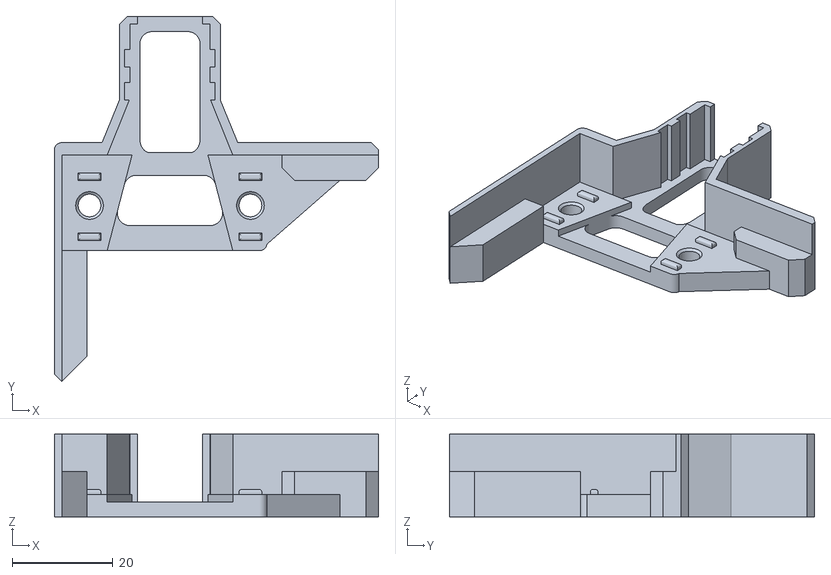
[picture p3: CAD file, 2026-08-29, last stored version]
stl/en4max-buildplatecornerguide-left.stl
64.5 x 72.6 x 16.5

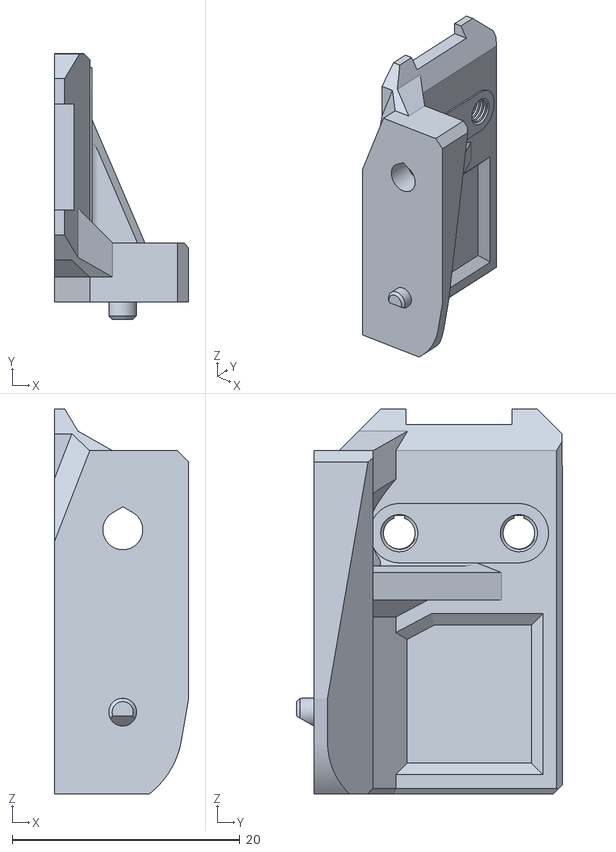
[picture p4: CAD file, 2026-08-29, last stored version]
stl/BTT-Eddy_Adapter90deg_v05.stl
11.8 x 23.3 x 33.8

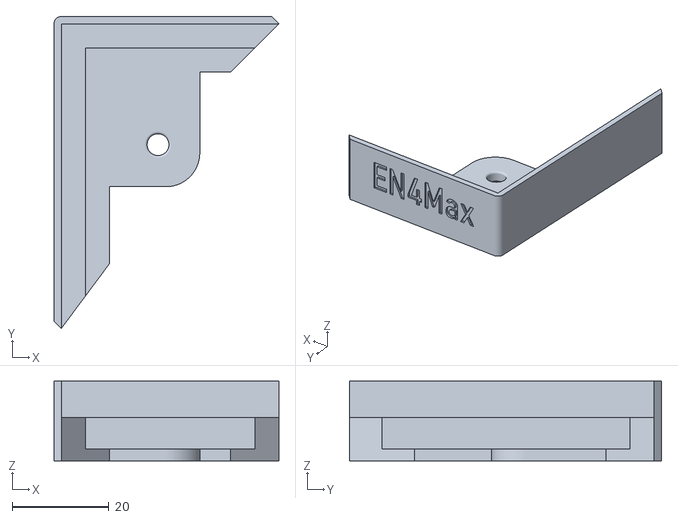
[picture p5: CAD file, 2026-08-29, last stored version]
stl/en4max-buildplatecornerguide-right.stl
46.5 x 64.5 x 16.5

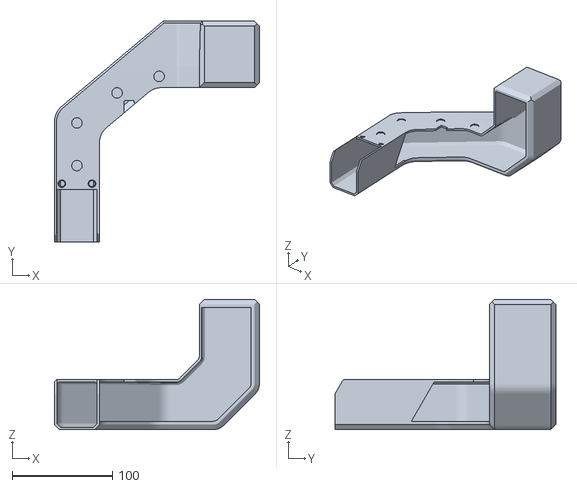
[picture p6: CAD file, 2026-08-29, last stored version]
stl/ecc2-poop-chute-magnetic-snap-in-place-15x10-20x10mm_magnets_logo.stl
204.4 x 220.0 x 130.0

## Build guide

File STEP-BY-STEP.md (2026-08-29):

# Modern Klipper on the Elegoo Neptune 4 Max, step by step

> [Versão em português](PASSO-A-PASSO.md) · [The Z-offset that refuses to obey](Z-OFFSET.md)

The Neptune 4 Max ships from the factory with a Klipper build from **2022**. You can run the **2025**
one (0.13.0), and this guide shows exactly how, command by command, with what each one does and
what you should see on screen.

> **Without S&M Makers none of this would exist.** All the work of porting modern Klipper to this
> machine is theirs. This guide walks through their process, with the pitfalls we hit in practice.
> Watch the **[@SandMMakers video](https://www.youtube.com/watch?v=Aoy3sI1lv1g)** and read the
> [original tutorial](https://sandmmakers.com/Projects/Neptune4MaxLatestKlipper/Directions.html).

You do **not** need a USB stick, an SD card, a screwdriver, or to open the printer. It is all done
over the network.

---

## Contents

1. [Before you start](#1-before-you-start)
2. [Find the printer's IP](#2-find-the-printers-ip)
3. [Connect to the printer](#3-connect-to-the-printer)
4. [Recon (read-only, changes nothing)](#4-recon-read-only-changes-nothing)
5. [Make a backup](#5-make-a-backup-do-not-skip-this)
6. [Install](#6-install)
7. [Verify](#7-verify)
8. [What to do afterwards](#8-what-to-do-afterwards)
9. [Rolling back](#9-rolling-back)
10. [Common problems](#10-common-problems)

---

## 1. Before you start

### What you need

- The printer **powered on**, **not printing**, on the **same network** as your computer
- A computer running Windows 10/11, Mac or Linux
- About 30 minutes

### What is about to happen, in plain words

The printer is a little Linux computer. You are going to log into it over the network (that's
**SSH**), swap the Klipper folder for a newer one, recompile two small things, and reboot.

Only two things get replaced, the `~/klipper` folder and the `/usr/local/bin/klipper_mcu` program.
The printer's main chip (the **STM32 MCU**) is **never touched**. The author himself advises against
it, because it requires taking the machine apart.

### The risks, plainly

Touching firmware carries risk. The rollback path exists and is in [section 9](#9-rolling-back), but
you are the one standing next to the printer. If power drops mid-install, you may have to reflash the
Elegoo firmware from a USB stick.

**Do the [backup in section 5](#5-make-a-backup-do-not-skip-this).** It is the difference between a
scare and a problem.

---

## 2. Find the printer's IP

On the printer's panel go to **Settings**. The IP appears on screen, something like `192.168.0.50`.

If it isn't there, open your router's admin page and look through the connected devices for a name
like `mkspi`.

Write that number down. It appears in almost every command below. **Wherever this guide says
`YOUR_IP`, substitute yours.**

---

## 3. Connect to the printer

### Open a terminal

| System | How |
|---|---|
| **Windows** | Press `Win`, type `powershell`, Enter |
| **Mac** | `Cmd + Space`, type `terminal`, Enter |
| **Linux** | `Ctrl + Alt + T` |

### Log in

```bash
ssh mks@YOUR_IP
```

The first time it asks whether you trust the machine. Type `yes` and Enter.

Then it asks for the password. The default is this.

```
makerbase
```

> **While you type the password, nothing appears on screen.** No asterisks, no dots. It looks like
> the keyboard stopped working. That is intentional, every Linux terminal does this. Type it and
> press Enter.

It worked if the text before your cursor becomes something like `mks@mkspi:~$`.

### Optional but recommended, log in without a password

If you are going to repeat these steps, install an access key. **Log out** (`exit`) and, on your own
computer, run this.

```bash
ssh-keygen -t ed25519 -N "" -f ~/.ssh/id_ed25519
ssh-copy-id mks@YOUR_IP
```

Windows has no `ssh-copy-id`. Use this instead. It avoids duplicating the key if you run it twice.

```powershell
type $env:USERPROFILE\.ssh\id_ed25519.pub | ssh mks@YOUR_IP "mkdir -p ~/.ssh; chmod 700 ~/.ssh; touch ~/.ssh/authorized_keys; K=$(cat | tr -d '\r'); grep -qxF \"$K\" ~/.ssh/authorized_keys || echo \"$K\" >> ~/.ssh/authorized_keys; chmod 600 ~/.ssh/authorized_keys"
```

### One thing that confuses people, `sudo` still asks for a password

Some commands need administrator power, they start with `sudo`. **Even with the key installed,
`sudo` asks for the password.** That is normal. Type `makerbase` when prompted.

---

## 4. Recon (read-only, changes nothing)

None of these four commands alter anything. Run them **inside the printer** (after `ssh`).

### 4.1 Which Elegoo firmware is installed

This is the single most important piece of information in the whole process.

```bash
grep -rhoE "1\.[0-9]+\.[0-9]+\.[0-9]+" /home/mks/Desktop/myfile/ 2>/dev/null | sort | uniq -c | sort -rn | head -3
```

What you should see, the number that repeats most is the right one.

```
     97 1.2.3.4
      1 Binary file /home/mks/Desktop/myfile/znp/znp_tjc_klipper/build/... matches
```

Here the firmware is **1.2.3.4**. Write yours down.

### 4.2 Which modern Klipper versions exist for it

```bash
git ls-remote --tags https://github.com/sandmmakers/klipper.git | grep -oE 'sandmmakers-[A-Za-z0-9.-]+' | grep -v '\^{}' | sort -u
```

Example output.

```
sandmmakers-ElegooNeptune4Max-v1.2.3.4-v0.13.0-0-1
sandmmakers-ElegooNeptune4Max-v1.2.3.4-v0.13.0-51-1
```

How to read that name.

```
sandmmakers-ElegooNeptune4Max-v1.2.3.4-v0.13.0-51-1
                              └──┬───┘ └──┬───┘ └┬┘
                    Elegoo firmware   Klipper   extra commits
```

> **The rule you cannot break.** The middle part must be **exactly** the firmware you noted in
> 4.1. If your firmware is `1.2.3.4`, only a tag with `v1.2.3.4` will do. Installing one built for a
> different firmware breaks the printer.

Among the compatible ones, pick the one with the **highest number of extra commits** (in the example,
`-51-1`).

**No tag matches your firmware?** Then you must update the Elegoo firmware first, and that process is
manual. See [section 10](#10-common-problems).

**Nothing at all, with an error?** The printer probably has no internet. It needs real internet
access, seeing your computer is not enough.

### 4.3 Is there disk space?

```bash
df -h /
```

```
Filesystem      Size  Used Avail Use% Mounted on
/dev/mmcblk1p2  6.6G  4.9G  1.7G  75% /
```

You need at least **800 MB** in the `Avail` column. If you have less, delete old gcodes from
`~/gcode_files`.

### 4.4 Is the printer printing?

```bash
curl -s http://localhost:7125/printer/objects/query?print_stats | grep -o '"state": "[a-z]*"'
```

It must say `"state": "complete"`, `"standby"` or `"cancelled"`. **If it says `"printing"`, stop
here** and wait for the print to finish.

---

## 5. Make a backup (do not skip this)

The installer keeps copies inside the printer itself. That covers 95% of problems, but not a
corrupted memory card. So take a copy **off the machine**.

Run this **on your computer**, not inside the printer. Type `exit` first.

**Windows, PowerShell.**

```powershell
cd $env:USERPROFILE\Desktop
ssh mks@YOUR_IP "tar czf - -C / home/mks/klipper_config home/mks/klipper usr/local/bin/klipper_mcu* 2>/dev/null" > backup-neptune.tar.gz
```

**Mac or Linux.**

```bash
cd ~/Desktop
ssh mks@YOUR_IP "tar czf - -C / home/mks/klipper_config home/mks/klipper usr/local/bin/klipper_mcu* 2>/dev/null" > backup-neptune.tar.gz
```

It takes a few minutes and produces a file of a few hundred MB on your Desktop.

**Check that the backup is good.** An unverified backup is not a backup.

```bash
gzip -t backup-neptune.tar.gz && echo "BACKUP OK"
```

If `BACKUP OK` appears, carry on. If nothing appears or it errors, do it again.

> The most valuable thing in that archive is `klipper_config/printer.cfg`. It holds all of your
> machine's calibration, and it is the only file you cannot download again from the internet.

---

## 6. Install

Log back into the printer (`ssh mks@YOUR_IP`).

**Before pasting anything**, set these two variables to YOUR values from section 4. Every command
below uses them.

```bash
FW=1.2.3.4
TAG=sandmmakers-ElegooNeptune4Max-v1.2.3.4-v0.13.0-51-1
```

Check they are right before continuing.

```bash
echo "firmware=$FW  tag=$TAG"
```

### 6.1 Stop the services

```bash
sudo systemctl stop klipper
sudo systemctl stop klipper_mcu
sudo systemctl stop makerbase-client
```

It asks for the password (`makerbase`) the first time. From here on the printer stops responding in
Fluidd/Mainsail until the end, that is expected.

### 6.2 Save the backups

```bash
cp ~/klipper_config/printer.cfg ~/klipper_config/printer.cfg.stock.v$FW
mv ~/klipper ~/klipper.stock.v$FW
sudo mv /usr/local/bin/klipper_mcu /usr/local/bin/klipper_mcu.stock.v$FW
```

Confirm all three exist before moving on.

```bash
ls -d ~/klipper.stock.v$FW /usr/local/bin/klipper_mcu.stock.v$FW ~/klipper_config/printer.cfg.stock.v$FW
```

If any of the three is missing, **stop**. Without them there is no way back.

### 6.3 Adjust the configuration file

Modern Klipper **removed** a setting called `max_accel_to_decel`. If it stays in the file, Klipper
will not start, and the error message does not explain why very well.

```bash
sed -i "s/^max_accel_to_decel:/#max_accel_to_decel:/" ~/klipper_config/printer.cfg
sed -i "/{% set RUN_DECEL/d" ~/klipper_config/printer.cfg
sed -i "s/ ACCEL_TO_DECEL={RUN_DECEL}//" ~/klipper_config/printer.cfg
```

Check no active line is left.

```bash
grep -nE "^max_accel_to_decel|RUN_DECEL" ~/klipper_config/printer.cfg
```

Nothing at all, or only lines starting with `#`, means you are good.

### 6.4 Download the new Klipper

```bash
git clone https://github.com/sandmmakers/klipper.git ~/klipper.sandmmakers
ln -sfn ~/klipper.sandmmakers ~/klipper
cd ~/klipper
git checkout $TAG
```

Confirm you got the right one.

```bash
git describe --tags
```

It must return exactly your `$TAG`.

### 6.5 Compile part 1 of 2

```bash
cd ~/klipper
sudo rm -f klippy/chelper/c_helper.so
~/klippy-env/bin/python2 klippy/chelper/__init__.py
~/klippy-env/bin/python2 -m compileall klippy
```

> **Deleting `c_helper.so` first is mandatory.** If that file does not exist when the printer
> boots, Elegoo's screen module copies an incompatible version over it, and Klipper dies with
> `undefined symbol: extruder_stepper_free`. Recompiling fixes it, but it's a scare you can avoid by
> doing it in the right order.

### 6.6 Compile part 2 of 2 (the slow one)

The original tutorial tells you to run `make menuconfig` and tick "Linux process" on a blue screen.
You can skip that screen by writing the option directly. The result is identical.

```bash
cd ~/klipper
make clean
echo "CONFIG_MACH_LINUX=y" > .config
make olddefconfig
```

Verify the configuration took.

```bash
grep CONFIG_BOARD_DIRECTORY .config
```

It must show `CONFIG_BOARD_DIRECTORY="linux"`. If it doesn't, **do not continue**.

Now compile for real. **This part takes 5 to 15 minutes and looks frozen.** It isn't. Don't close the
window.

```bash
make clean
make
```

Check the file came out.

```bash
ls -la out/klipper.elf
```

### 6.7 Install what you compiled

```bash
sudo mv out/klipper.elf /usr/local/bin/klipper_mcu.sandmmakers
sudo ln -sfn /usr/local/bin/klipper_mcu.sandmmakers /usr/local/bin/klipper_mcu
```

### 6.8 Reboot

```bash
sudo reboot now
```

The connection will drop, that is expected. Wait 45 to 90 seconds.

---

## 7. Verify

Log back in (`ssh mks@YOUR_IP`) and run this.

### The installed version

```bash
grep -m1 "Git version" ~/klipper_logs/klippy.log
```

```
Git version: 'sandmmakers-ElegooNeptune4Max-v1.2.3.4-v0.13.0-51-1-0-g8dc12fe4'
```

### Did Klipper come up?

```bash
curl -s http://localhost:7125/printer/info | tr ',' '\n' | grep -E 'state|software_version'
```

```
{"result": {"state_message": "Printer is ready"
 "software_version": "sandmmakers-ElegooNeptune4Max-v1.2.3.4-v0.13.0-51-1-0-g8dc12fe4"
 "state": "ready"
```

It must say `"state": "ready"`.

### Did both processors show up?

```bash
grep -oE "Loaded MCU '[a-z]+' [0-9]+ commands" ~/klipper_logs/klippy.log | tail -2
```

```
Loaded MCU 'mcu' 105 commands
Loaded MCU 'rpi' 127 commands
```

`mcu` is the printer's original STM32. `rpi` is the one you just compiled. **Both must appear.**

---

## 8. What to do afterwards

**Before printing anything**, on the printer's panel.

1. **Auto bed leveling**
2. **Set the Z-offset**

The old calibration is not carried over reliably by the new Klipper.

> **If the Z-offset seems to do nothing at all, it is not your fault.** This machine has a known
> defect with three causes, and the fix is in **[Z-OFFSET.md](Z-OFFSET.md)**. Worth reading before
> you waste time thinking you botched the calibration, we did.

### Two odd things that are normal

**1. An error when saving the bed mesh.** After leveling from the panel and hitting save, an error
may appear in the Fluidd/Mainsail console. It is harmless. Send a `FIRMWARE_RESTART` (or reboot the
printer) and you are done, the mesh **was saved** and will be used.

**2. The "performance modes" changed.** Those speed modes on the panel relied on `max_accel_to_decel`,
which was removed from Klipper. They no longer control deceleration. In practice you may notice a
difference on part corners. To restore the old behaviour, add this under `[printer]` in your
`printer.cfg`.

```ini
minimum_cruise_ratio: 0
```

---

## 9. Rolling back

This works if you did section 6.2 and all three copies exist.

```bash
FW=1.2.3.4                    # same as section 4.1

sudo systemctl stop klipper
sudo systemctl stop klipper_mcu
sudo systemctl stop makerbase-client

# keep the new config before overwriting it
cp ~/klipper_config/printer.cfg ~/klipper_config/printer.cfg.new
cp ~/klipper_config/printer.cfg.stock.v$FW ~/klipper_config/printer.cfg

rm ~/klipper
mv ~/klipper.stock.v$FW ~/klipper

sudo rm -f /usr/local/bin/klipper_mcu
sudo mv /usr/local/bin/klipper_mcu.stock.v$FW /usr/local/bin/klipper_mcu

sudo reboot now
```

> **Rolling back restores the factory `printer.cfg`.** Every bit of calibration you did after the
> install stays in `printer.cfg.new` and **does not come back on its own**. To recover a setting,
> open both files side by side and copy what you need.

The `~/klipper.sandmmakers` folder stays where it is, so reinstalling later is quick.

---

## 10. Common problems

### `Permission denied` when connecting over SSH

Wrong password, or someone changed it. The default is `makerbase`. If another mod was installed
before (OpenNept4une, for example), the password may be different.

### `Host key verification failed`

Happens when the printer was reflashed and its "identity" changed. On your computer run this.

```bash
ssh-keygen -R YOUR_IP
```

Then connect again.

### Windows says `ssh` is not recognized

Go to **Settings → Apps → Optional features → Add a feature** and install the **OpenSSH Client**.
Close and reopen PowerShell.

### Klipper won't start after installing

Find out why.

```bash
tail -30 ~/klipper_logs/klippy.log
```

The two most common errors.

| Message | Cause | Fix |
|---|---|---|
| `Option 'max_accel_to_decel' is not valid` | Section 6.3 didn't take | Redo 6.3 and send `FIRMWARE_RESTART` |
| `undefined symbol: extruder_stepper_free` | The wrong `c_helper.so` was copied over | Redo section 6.5 entirely |

### There is no modern Klipper for my firmware

Then the road is **manual**. You must update the Elegoo firmware first.

1. Download from [elegoo.com/pages/download](https://www.elegoo.com/pages/download)
2. **Mainboard.** Copy the `ELEGOO_UPDATE_DIR` folder onto an empty USB stick, plug it into the
   printer, and on the panel go to Settings → About Machine → down arrow → Confirm. Takes 1 to 2 minutes.
3. **Screen.** Copy the `.tft` file onto the SD card that came with the printer. This one needs the
   back cover of the screen removed with a 2 mm hex key, insert the SD, power on, wait for the
   update, then open it again to take the card out.
4. Redo bed leveling and the Z-offset.

Then go back to [section 4](#4-recon-read-only-changes-nothing).

> The Elegoo update **can erase your `printer.cfg`** and may force leveling into Standard mode
> (6x6). If you used **Professional Mode**, you will have to set it up again.

---

## Credits

All the heavy lifting belongs to **S&M Makers**.

- [Original tutorial](https://sandmmakers.com/Projects/Neptune4MaxLatestKlipper/Directions.html)
- [github.com/sandmmakers/klipper](https://github.com/sandmmakers/klipper)
- [@SandMMakers video](https://www.youtube.com/watch?v=Aoy3sI1lv1g)

**No warranty.** Touching firmware carries risk. The rollback path exists and works, but you are the
one standing next to the printer.

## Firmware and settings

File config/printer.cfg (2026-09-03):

####################################################################################
# Machine type: NEPTUNE 4 MAX
# Current configuration version: V1.6
# Date：2024-6-24
####################################################################################
# This product (Neptune 4/4pro/4plus/4max) adopts Klipper firmware 
# and does not support users to update the official klipper/fluidd
# /moonraker by themselves, otherwise the machine will not work properly.
# If you want to DIY and are an expert or interested in this field, 
# we recommend that you prepare your own tools for burning images so 
# that you can restore them if problems arise. Please contact after-sales 
# support team for tutorials on burning images. Thank you for your cooperation!
####################################################################################
# This file contains common pin mappings for ZNP-K1-V2.0 
# boards. To use this config, the firmware should be compiled for the
# STM32F402. When running "make menuconfig", enable "extra low-level
# configuration setup", select the 32KiB bootloader, and serial (on
# USART1 PA10/PA9) communication.

# The "make flash" command does not work on the ZNP-K1-V2.0. Instead,
# after running "make", copy the generated "out/klipper.bin" file to a
# file named "elegoo_k1.bin" on an SD card and then restart the ZNP-K1-V2.0
# with that SD card.

# See docs/Config_Reference.md for a description of parameters.
####################################################################################



[include plr.cfg]
# DISABLED 2026-08-28: [include KAMP_Settings.cfg]
[include eddy.cfg]  # BTT Eddy Duo -- 2026-08-28, mcu/probe/temp/bed_mesh do Eddy

[mcu]
# The hardware use USART1 PA10/PA9 connect to RK3328
serial: /dev/ttyS0
restart_method: command

[stepper_x]
step_pin:PC14
dir_pin:PC13
enable_pin:!PC15
microsteps: 16
rotation_distance: 40
full_steps_per_rotation:200
endstop_pin:tmc2209_stepper_x:virtual_endstop
position_min: -0.1
position_endstop: 0
position_max: 430.1
homing_speed:50
homing_retract_dist:0
homing_positive_dir:false

[stepper_y]
step_pin:PB4
dir_pin:PB3
enable_pin:!PC15
microsteps:16
rotation_distance: 40
full_steps_per_rotation:200
endstop_pin:tmc2209_stepper_y:virtual_endstop
position_min: -0.1
position_endstop:0 
position_max:430.1
homing_speed:50
homing_retract_dist:0
homing_positive_dir:false

[stepper_z]
step_pin:PC10
dir_pin:!PA13
enable_pin: !PC11
microsteps: 16
rotation_distance: 8
full_steps_per_rotation: 200
endstop_pin:probe:z_virtual_endstop
# ATENCAO, leia antes de mexer nesta linha.
# Em 2026-08-29 foi tentado trocar por ^PA11, a sonda fisica original. NAO FUNCIONA
# NESTA MAQUINA porque o sensor foi REMOVIDO da cabeca na instalacao do Eddy. O cabo
# continua na placa e o pino flutua em nivel alto por causa do pull-up, o que faz o
# Klipper achar que ha um fim de curso acionado. Invertendo para ^!PA11 ele passa a ler
# solto SEMPRE, inclusive no contato, e o eixo desce ate o fim. Foi testado e o Igor
# precisou cortar a energia. So volte a considerar PA11 se um sensor de contato for
# fisicamente reinstalado, e valide antes com QUERY_ENDSTOPS apertando o bico com o dedo.
                          # REVALIDAR com papel antes de imprimir

##  Z-position of nozzle (in mm) to z-endstop trigger point relative to print surface (Z0)
##  (+) value = endstop above Z0, (-) value = endstop below
##	Increasing position_endstop brings nozzle closer to the bed
##  After you run Z_ENDSTOP_CALIBRATE, position_endstop will be stored at the very end of your config
#position_endstop:-5
position_max: 482.5
position_min: -5 
homing_speed: 8
homing_retract_dist: 1.5   # 2026-08-29: era 5 (heranca da sonda fisica). Com o Eddy, recuar 5mm apos o gatilho leva a bobina a ~7mm, fora da faixa de 4.05mm -> 2a passada cega -> Eddy current sensor error. 1.5 mantem a bobina em ~3.5mm.
second_homing_speed: 3

[extruder]
step_pin:PA5
dir_pin:!PA6
enable_pin:!PA4
microsteps:16
rotation_distance: 29.0  #31.4	#Bondtech 5mm Drive Gears
gear_ratio: 52:10
full_steps_per_rotation: 200	#200 for 1.8 degree, 400 for 0.9 degree
nozzle_diameter: 0.6
filament_diameter: 1.750
min_temp: 0
max_temp: 310
heater_pin: PA7
sensor_type:NTC 100K MGB18-104F39050L32
sensor_pin: PA1
max_power: 1
control : pid
pid_kp : 25.989
pid_ki : 3.397
pid_kd : 49.705
pressure_advance: 0.020
pressure_advance_smooth_time: 0.04
instantaneous_corner_velocity: 2.5
max_extrude_only_distance: 300
max_extrude_only_velocity:60
max_extrude_only_accel:5000
max_extrude_cross_section: 5   # bico 0.6 - protecao restaurada (era 9999999 do bico 1mm)
min_extrude_temp:100

[verify_heater extruder]
max_error: 120
check_gain_time:10
hysteresis: 10
heating_gain: 2

[heater_bed]
heater_pin:PB10
sensor_type: NTC 100K MGB18-104F39050L32
sensor_pin: PA0
max_power: 1.0
control : pid
pid_kp : 75.397
pid_ki : 0.823
pid_kd : 1727.531
pwm_cycle_time: 0.016
min_temp: 0
max_temp: 110

[verify_heater heater_bed]
max_error: 120
check_gain_time:300
hysteresis: 10
heating_gain: 2

[heater_fan fan1]
pin: PC7
shutdown_speed: 1

# fan for printed model FAN2
[fan]
pin: PB7

# [fan_generic fan3]
# pin: PC9

# [fan_generic fan4]
# pin: PA8

# [fan_generic fan5]
# pin: PA15


[printer]
kinematics:cartesian
max_velocity: 500
max_accel: 2000
#max_accel_to_decel: 20000
max_z_velocity: 10
max_z_accel: 100
square_corner_velocity: 5.0


[input_shaper]
#shaper_type_x = mzv
#shaper_freq_x = 62.2
#shaper_type_y = ei
#shaper_freq_y = 30.0
# damping_ratio_x: 0.1
# damping_ratio_y: 0.1


####################################################################
#	Homing and Gantry Adjustment Routines
#####################################################################
[idle_timeout]
timeout: 3600
gcode:
  {% if printer[printer.toolhead.extruder].temperature > 140 %}   # Reduce the hot end temperature after 10 minutes
  {action_respond_info("Extruder powered down on idle timeout.")}
  SET_HEATER_TEMPERATURE HEATER=extruder TARGET={120}       # After pausing printing, reduce nozzle temperature to 50℃
  M84 E
  # SET_IDLE_TIMEOUT TIMEOUT=259200       # Timer duration 3 days.
  {% else %}
  TURN_OFF_HEATERS
  M84 E
  {% endif %}

# Home automatico: sobe 7mm para liberar a borracha, homeia XY e deixa o
# proprio Eddy descer de qualquer altura ate encontrar a mesa.
[homing_override]
axes: xyz
gcode:
    {% set tudo = 'X' not in params and 'Y' not in params and 'Z' not in params %}
    {% set pede_z = tudo or 'Z' in params %}
    {% set eixos = printer.toolhead.homed_axes %}
    {% set z_homeado = 'z' in eixos %}
    {% if not z_homeado %}
        SET_KINEMATIC_POSITION Z=0 SET_HOMED=Z
        G91
        G0 Z7 F300
    {% elif printer.toolhead.position.z|float < 7 %}
        G90
        G0 Z7 F300
    {% endif %}
    G90

    {% if tudo or 'X' in params or (pede_z and 'x' not in eixos) %}
        G28 X
    {% endif %}
    {% if tudo or 'Y' in params or (pede_z and 'y' not in eixos) %}
        G28 Y
    {% endif %}

    {% if pede_z %}
        G0 X239.25 Y194.55 F6000
        SET_KINEMATIC_POSITION Z=482.5 SET_HOMED=Z
        G28 Z
    {% elif not z_homeado %}
        SET_KINEMATIC_POSITION CLEAR_HOMED=Z
    {% endif %}

[gcode_macro G29]
gcode:
      M400
      BED_MESH_CLEAR
      G28
      _BED_MESH_CALIBRATE profile=default mesh_min=20,30 mesh_max=360,400 probe_count=6 algorithm=bicubic
      M400
      G4 P2000
      G91 
      G1 Z5 F300 
      G90
      G28 Z
      G1 X215 Y215 F12000
      G1 Z0 F300

#####################################################################
# 	Probe
#####################################################################

# --- [probe] classico DESATIVADO 2026-08-28, substituido pelo [probe_eddy_current btt_eddy] em eddy.cfg ---
# [probe]
# pin:^PA11
# x_offset: -24.25
# y_offset: 20.45
# z_offset: 2.110   # confirmado com calibre de lamina 2026-07-27
# speed: 10.0
# samples: 2
# samples_result: median
# sample_retract_dist: 3.0
# samples_tolerance: 0.05
# samples_tolerance_retries: 5
# Para reverter pro probe fisico: descomentar acima E comentar [include eddy.cfg]

# --- [bed_mesh] classico DESATIVADO 2026-08-28, movido pra eddy.cfg (mesmos valores por ora) ---
# [bed_mesh]
# speed:200                
# horizontal_move_z:10     
# mesh_min:20,30
# mesh_max:395,400
# probe_count:6,6          
# algorithm:bicubic
# bicubic_tension:0.2
# mesh_pps: 2, 2   
# fade_start:5.0
# fade_end:30.0  


#####################################################################
# LED Control
#####################################################################

[gcode_macro FLASHLIGHT_SWITCH]
description: Switch Hotend LEDs
gcode:
  RUN_SHELL_COMMAND CMD=FLASHLIGHT

[gcode_shell_command FLASHLIGHT]
command: sh /home/mks/sled2.sh
timeout: 5.

[gcode_macro MODLELIGHT_SWITCH]
description: Switch Logo LEDs
gcode:
  RUN_SHELL_COMMAND CMD=MODLELIGHT

[gcode_shell_command MODLELIGHT]
command: sh /home/mks/sled1.sh
timeout: 5.
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

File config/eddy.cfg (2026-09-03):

# eddy.cfg -- config ativa do BTT Eddy Duo nesta N4Max (fork S&M Makers, base 0.13.0)
# usar z_offset, NAO descend_z (rename so existe em Klipper pos-2026-03-18, mais novo que este fork)
#
# DECISAO DO IGOR 2026-08-28: altura de montagem 0,94mm (bico encostando na mesa -> face do coil
# a 0,94mm da mesa). Abaixo do recomendado pelo manual BTT (2-3mm), risco mecanico assumido
# conscientemente. Mitigacoes de config abaixo compensam a folga menor:
# - bed_mesh mantido SEM METHOD=scan (usar so `BED_MESH_CALIBRATE` simples): cada ponto sobe pra
#   horizontal_move_z (10mm) antes de mover em XY, dando folga cheia entre leituras. O modo
#   METHOD=scan/rapid_scan faz varredura CONTINUA rente a mesa (a real vantagem de velocidade do
#   Eddy) -- com 0,94mm de folga isso e risco de verdade (bump/resíduo/verruga na mesa durante o
#   passe).
#   REAVALIADO 2026-08-29 -- DECISAO DO IGOR: USAR rapid_scan. A restricao acima nasceu de
#   medo do mount de 0,94mm, mas quem define a folga do bico no passe e o HORIZONTAL_MOVE_Z
#   (2.5mm), nao a altura de montagem da bobina. Com 2.5mm o bico tem folga normal e a bobina
#   fica a 3.44mm, dentro da faixa calibrada de 4.05mm. rapid_scan e a razao de existir do Eddy.
# - mesh_min/mesh_max mantidos com boa margem das bordas (ja eram 20,30 / 395,400 num prato de
#   430x430, ~20-30mm de recuo -- mantido, some com o offset do sensor quando ele for medido).
# - horizontal_move_z: 10 (igual ao [bed_mesh] antigo) -- folga de sobra entre pontos.
# - safe_z_home z_hop: 10 (ja existia) -- mantido, cobre o homing.

[mcu eddy]
serial: /dev/serial/by-id/usb-Klipper_rp2040_SEU_SERIAL_AQUI-if00  # troque pelo SEU: ls /dev/serial/by-id/
# confirmado 2026-08-28 (rodada 6): mcu conecta, protocolo identico ao host (mesma tag de build)

[probe_eddy_ng btt_eddy]
sensor_type: ldc1612
i2c_mcu: eddy
i2c_bus: i2c0f
x_offset: -33.34
y_offset: 20
# CONFIRMADO 2026-08-28. Medida real: 32.33mm do centro do bico ao centro do parafuso/corpo do
# Eddy (paquimetro, coil e concentrica com o furo de fixacao -- nao precisa abrir a carcaca).
# SINAL corrigido depois de checar [stepper_x] no printer.cfg real: position_endstop=0,
# homing_positive_dir=false -> fim de curso X fica no lado X=0 (esquerda). Igor confirmou o Eddy
# fica do lado do fim de curso -> sensor esta a ESQUERDA do bico, nao a direita como foi dito
# antes. x_offset NEGATIVO. Isso bate com TODOS os relatos da comunidade (-18 a -41mm, todos
# negativos) -- convergencia forte, tratada como confirmacao do sinal.
# y_offset MEDIDO 2026-08-29: Igor mediu 20mm. Sensor fica ATRAS e a esquerda do bico -> o ponto
# do prato sob a bobina tem Y maior que o do bico -> y_offset POSITIVO. x_offset remedido no mesmo
# dia: 33.34 (antes estava 32.33, digito trocado). ATENCAO: a [bed_mesh default] gravada no
# printer.cfg foi sondada com y_offset=0 -> esta 20mm fora do lugar, REFAZER.
# z_offset REMOVIDO DAQUI 2026-08-29. Enquanto ele estava escrito neste arquivo incluido,
# todo SAVE_CONFIG apos um PROBE_CALIBRATE falhava com "conflicts with included value":
# o Klipper nao sobrescreve por autosave um valor que veio de um include. Agora quem manda
# e o bloco autosave no fim do printer.cfg, entao o PROBE_CALIBRATE grava normalmente.
# Para ver o valor vigente: ZOFFSET. Para ajustar imprimindo: SOBE / DESCE / ZOFFSET_SALVAR.
# (era "z_offset: 1.95")
# aproximacao inicial so pra rodar a calibracao -- PROBE_EDDY_CURRENT_CALIBRATE ajusta a curva real
#speed: 5.0
#samples: 2
#samples_result: median
#sample_retract_dist: 1.0
# calibrate: (nao setar antes de calibrar -- neste fork 'calibrate' NAO e path de arquivo, e a
# string inline de pares freq:z que o PROBE_EDDY_CURRENT_CALIBRATE grava sozinho via SAVE_CONFIG.
# Botar um path aqui quebra o boot: 'could not convert string to float' -- ja aconteceu uma vez.)

# [temperature_probe btt_eddy] -- REMOVIDO POR ORA 2026-08-28. Este fork nao tem sensor_factory
# dedicada pro chip do Eddy (grep em klippy/extras/*.py -- so existe thermistor/temperature_mcu/etc,
# nenhuma p/ ldc1612). O objeto exige 'sensor_type:' obrigatorio (herda de PrinterHeaterGeneric via
# heaters.setup_sensor) e sem isso o Klipper nao sobe. NAO e essencial p/ sondar -- e so compensacao
# de drift termico opcional. Investigar depois: 'sensor_type: temperature_mcu' + 'sensor_mcu: eddy'
# (usa a temperatura interna do proprio RP2040 do Eddy como proxy) e o candidato mais plausivel,
# mas NAO testado ainda -- nao adicionar sem confirmar que nao quebra o boot de novo.

[bed_mesh]
speed: 200
horizontal_move_z: 2.5
mesh_min: 20,25   # 2026-08-29: limite real, nao estetico. Em X o bico vai para ponto+33.34,
                  # entao X20 leva o bico a 53.34. Em Y o bico vai para ponto-20, entao Y25
                  # leva o bico a 5, quase no batente da frente. X abaixo de 20 faria a
                  # bobina passar por cima da borracha de limpeza (X0-5, 7mm de altura).
mesh_max: 390,410  # maximo alcancavel: bico em 390+33.34=423.34 contra position_max 430.1,
                   # e em Y 410-20=390. Medir alem disso exigiria o bico fora do curso.
# RECALCULADO 2026-08-28 com x_offset=-32.33 (sensor a ESQUERDA do bico). Formula do Klipper:
# posicao do bico ao sondar um ponto do mesh = ponto_mesh - offset. Com offset negativo, o bico
# tem que ir MAIS PRA DIREITA que o ponto sondado (bico = ponto + 32.33) -- entao o lado que
# encolhe e o mesh_max (direita), nao o mesh_min. Old mesh_max 395 -> bico precisaria ir a
# 395+32.33=427.33, quase no limite fisico (position_max 430.1 do [stepper_x], sem margem de
# seguranca). Novo mesh_max 360 -> bico vai a 360+32.33=392.33, dentro do range antigo com folga.
# mesh_min 20 mantido sem mudanca (bico so precisaria ir a 20+32.33=52.33, longe do limite fisico
# 0/-0.1, sobra folga -- o lado esquerdo nao e o gargalo aqui).
# y_offset assumido 0 -> mesh_min/mesh_max em Y nao mudam.
probe_count: 6,6
algorithm: bicubic
bicubic_tension: 0.2
mesh_pps: 2, 2
fade_start: 5.0
fade_end: 30.0

# Reference mesh: 2500 real Eddy readings on a heat-stabilized bed.
# Use: EDDY_MALHA [BED=50] [SOAK=300]
# When complete, run SAVE_CONFIG to persist the default profile.
[gcode_macro EDDY_MALHA]
description: Malha densa de toda a area util. Ex: EDDY_MALHA BED=50 SOAK=300
# Aquece a mesa, espera estabilizar, faz o soak, homeia e varre em movimento continuo.
# 70x70 = 4900 pontos em 370x385mm, cerca de 5,3mm de espacamento.
# A varredura em si e rapida; o tempo aqui e quase todo soak, que e o que faz a malha
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

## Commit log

2026-07-28 Documentacao bilingue PT-BR/EN, extra de Z-offset e pagina GitHub Pages
    - README.md: landing bilingue com todos os arquivos explicados
    - GUIDE-EN.md: tutorial completo em ingles
    - EXTRA-Z-OFFSET.md: por que o Z-offset nao obedece nesta maquina
    (znp_tjc_klipper zera no save_config, plr.cfg declara zero falso no boot,
    PROBE_CALIBRATE repete valor errado) + fix via macro G28 + o efeito
    colateral que quebra impressao
    - docs/index.html: pagina GitHub Pages com alternador PT/EN
    - LICENSE: MIT no wrapper, com nota sobre Klipper GPLv3 e S&M Makers
    - Credito a S&M Makers em destaque em todos os arquivos
2026-07-28 Corrige quebra de linha do strong dentro dos avisos na pagina
2026-07-28 Corrige _comum.bat, que derrubava os passos 2, 3 e 4
    Bug: o bloco "if not %IP%==... ( set /p TROCAR=Usar este IP? (S/n): )"
    tinha dois defeitos de cmd somados:
    1. O parentese de "(S/n)" fechava o bloco IF no meio, e o ":" seguinte
    derrubava o script com ": was unexpected at this time."
    2. Mesmo sem isso, %TROCAR% e expandido junto com o bloco inteiro, ANTES
    do set /p rodar - a resposta do usuario nunca seria lida.
    Efeito real: o passo 1 funcionava (nao existia ip.txt ainda) e criava o
    ip.txt. A partir do passo 2 o arquivo existia, o bloco era executado, e
    os passos 2, 3 e 4 morriam antes de fazer qualquer coisa.
    Correcao: fluxo com goto no lugar do bloco entre parenteses, colchetes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
2026-07-28 Passo 1 nao duplica mais a chave SSH; validado na impressora real
    O passo 1 fazia "cat >> authorized_keys" sem checar. Cada execucao
    adicionava outra copia da mesma chave. Agora compara antes de anexar.
    Duas armadilhas apareceram no teste real e as duas estao tratadas:
    - o "type" do Windows manda CRLF, entao a chave enviada nunca batia com
    a linha ja gravada e a comparacao falhava sempre. Corrigido com
    "tr -d '\r'" na chave e "sed -i 's/\r$//'" no arquivo do destino.
    - authorized_keys ja existente com CR ficava com linha duplicada
    "invisivel". O sed normaliza o arquivo antes de comparar.
    Verificado na Neptune 4 Max real (192.168.68.105), Klipper
    sandmmakers-v1.2.3.4-v0.13.0-51-1:
    - p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
2026-07-28 Passo a passo com os comandos exatos no lugar da automacao em .bat
    Um .bat promete "clica e funciona". Sustentar essa promessa exigiria testar
    a instalacao inteira numa maquina de fabrica, varias vezes. Só existe uma
    impressora disponivel e ela esta em producao, entao a promessa nao pode ser
    mantida. Comando na tela promete outra coisa - "voce esta no comando, aqui
    esta o que vai rodar e por que" - e essa da para sustentar.
    Os .bat foram removidos.
    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
2026-07-28 Remove o guia de automacao por agente; foco no passo a passo manual
2026-08-29 Guia do BTT Eddy, area para IA e README profissional
    Acrescenta o terceiro procedimento do repositorio, a sonda BTT Eddy, com o que
    foi medido e quebrado na maquina real.
    EDDY.md
    Guia completo: montagem e as tres medidas, a configuracao base com as contas
    que evitam estourar a faixa do sensor, a ordem correta da calibracao, o ritual
    de homing e a malha densa por varredura.
    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
2026-08-29 Reescreve o guia do Eddy por topicos e acrescenta hardware e pecas
    O EDDY.md passou de texto corrido para quinze topicos numerados, com indice
    navegavel e cada assunto isolado, para quem chega procurando um problema
    especifico achar sem ler o resto.
    Conteudo novo
    Hardware. Passa a constar que a sonda e a BTT Eddy Duo e que ela liga por
    USB, sem fio de dados na placa mae.
    Botao de BOOT. O botao fica na parte de cima da placa e a ordem importa.
    Segurar o botao primeiro, ligar o USB depois, e so entao soltar. Ligando o
    USB antes ele nao entra em modo de gravacao e parece defeito de placa.
    Pecas impressas. Adaptador do Eddy para a Neptune 4, suporte da borracha de
    limpeza usand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
2026-08-29 Prepara o repositorio para publicacao, ajusta estilo, adiciona STL e diagramas
    Padroniza PASSO-A-PASSO.md, STEP-BY-STEP.md e Z-OFFSET.md com as regras de
    escrita do README.md e EDDY.md (sem emoji, sem travessao, sem ponto e virgula
    ou dois pontos em prosa), sem alterar nenhum comando, valor ou procedimento.
    Corrige anchors quebrados em EDDY.md que perdiam acento na geracao do link.
    Cria links cruzados entre Z-OFFSET.md e EDDY.md para o bloco
    delayed_gcode KINEMATIC_POSITION que quebra o homing e o Z-offset pelo mesmo
    motivo.
    Reforca o reg_drive_current como causa mais comum de erro de sensor no
    README.md, EDDY.md, AGENTS.md e docs/index.html (pt e en), a pedido do dono
    do repositorio.
    Traz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
    [BTT-Eddy_Adapter90deg_v05.stl, BTT-Eddy_Adapter_v05.stl, ecc2-poop-chute-magnetic-snap-in-place-15x10-20x10mm_magnets_logo.stl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]
2026-08-29 Transforma o repositorio num guia conduzido por IA, com diagramas
    Um agente que recebe este repositorio agora pergunta ao usuario qual dos
    cinco caminhos ele quer antes de emitir qualquer comando, e conduz o
    procedimento com uma maquina de referencia inteira para explicar de onde
    vem cada numero.
    - MAQUINA-REFERENCIA.md: a Neptune 4 Max do autor por inteiro, hardware,
    valores gravados, cada alteracao e o motivo, macros e pendencias
    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
2026-08-30 Atualiza links para o novo nome do repositorio, N4Max
2026-08-30 Anota as 2 porcas de embutir M3 do adaptador do Eddy
2026-08-30 Adiciona diagrama do botao de BOOT do Eddy
2026-08-30 Atualiza z_offset e reg_drive_current para os valores da recalibracao de 29/08, marca a malha densa como concluida
2026-09-03 Adiciona o caminho do eddy-ng e o acervo de configuracao da maquina
    O BTT Eddy desta maquina saiu do driver probe_eddy_current e passou a usar o
    eddy-ng, com o zero do bico medido por tap a cada impressao em vez de um
    z_offset guardado.
    - EDDY-NG.md: guia completo. Diferenca entre Eddy e eddy-ng em linguagem
    simples, receita em 6 passos, o ovo-e-galinha do primeiro homing, como ler a
    calibracao, tabela dos 10 erros do caminho e o rollback de cada etapa.
    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
    [KAMP_Settings.cfg, eddy.cfg, eddyng_macros.cfg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]
2026-09-03 Deixa explicito que o risco e a responsabilidade sao de quem segue o guia
    Aviso no topo do README, onde se ve antes de qualquer procedimento, e reforco
    na secao de licenca: o material e compartilhado sem garantia e quem segue
    assume integralmente a responsabilidade pelo que acontecer com o equipamento.
    Versao curta tambem em ingles.
    No AGENTS.md, a IA passa a ser obrigada a dizer isso ao usuario antes do
    primeiro comando que toca na maquina, como informacao operacional e nao como
    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
2026-09-03 Corrige o que a auditoria achou e adiciona os cinco diagramas do eddy-ng
    Uma IA leu o repositorio inteiro fingindo ser um agente recebendo a maquina de
    um desconhecido, e apontou onde ela adivinharia ou quebraria a impressora de
    alguem. As correcoes:
    CONFIG CORROMPIDA (o achado mais grave)
    - config/eddy.cfg tinha [gcode_macro EDDY_MALHA] declarada quatro vezes, duas
    delas indentadas dentro do proprio corpo gcode:. O arquivo CARREGA (a maquina
    estava rodando assim), mas a macro registrada tem cabecalhos literais dentro
    do corpo e explodiria ao ser chamada -- e BED_MESH_CALIBRATE redireciona para
    ela. Corrigido na impressora e recopiado aqui.
    CONTRADICOES ENTRE DOCUMENTOS
    - AGENTS.md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
    [eddy.cfg]
2026-09-03 Redige o IP real da impressora para SEU_IP, evitando inconsistencia com o resto do repo
2026-09-03 Coloca o aviso de risco antes do titulo, para ser a primeira coisa que o leitor ve
2026-09-03 Troca os links PT/EN soltos por uma caixinha de idioma (tabela com bandeiras)
2026-09-03 Remove a tabela de valores superados do driver antigo, deixa so o estado atual eddy-ng
2026-09-03 Corrige Pendencias, o z_offset citado ali era do driver antigo e nao existe mais
2026-09-03 Remove a pasta stl/, mantem so o link do Printables do adaptador do Eddy
    [BTT-Eddy_Adapter90deg_v05.stl, BTT-Eddy_Adapter_v05.stl, ecc2-poop-chute-magnetic-snap-in-place-15x10-20x10mm_magnets_logo.stl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]
